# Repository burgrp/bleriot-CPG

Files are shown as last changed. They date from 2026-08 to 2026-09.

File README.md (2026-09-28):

# BleRiot Circulation Pump Group Controller

CPG is a mains-powered BleRiot node for controlling a circulation pump and a
motorized 3-way or 4-way valve in floor-heating and radiator-heating circuits.
It provides one switched output for the pump and two interlocked directional
outputs for a reversible valve actuator.

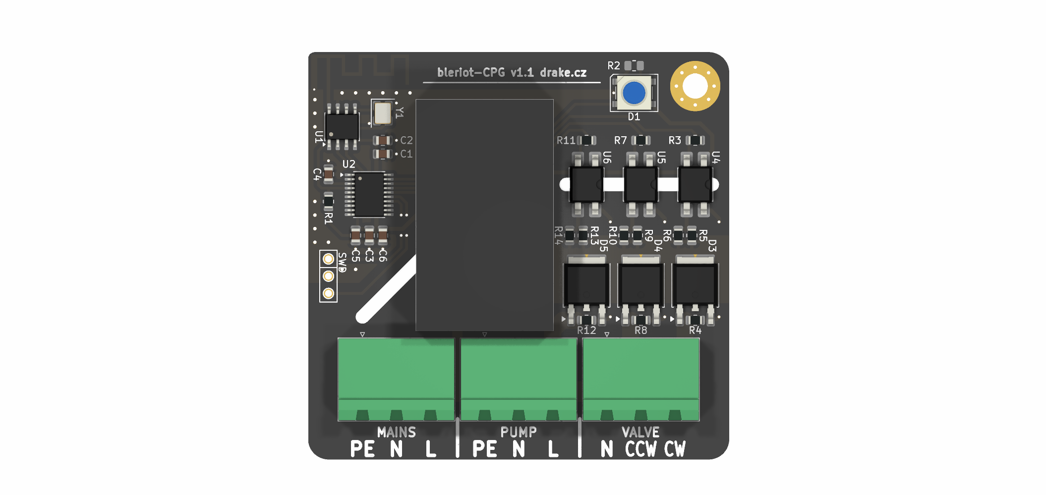
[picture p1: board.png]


The board is intended for supervisory heating control. Its triac channels are
on/off outputs; they are not phase-angle dimmers.

## Functions

- Circulation pump on/off control.
- Clockwise and counter-clockwise valve actuation.
- Firmware interlock preventing both valve directions from being energized at
  the same time.
- 100 ms break-before-make delay when changing valve direction; the latest
  command received during the delay wins.
- PAN2110 sub-GHz radio running the BleRiot register protocol.
- WS2812 status LED for local state indication.
- Onboard PY32F030 microcontroller and mains-to-3.3 V power module.

This arrangement supports common motorized mixing and diverting valves whose
actuator has a neutral connection and separate CW and CCW live inputs. Confirm
the actuator wiring and required reversal delay against its documentation.

## Connections

Connector numbering follows the KiCad schematic and PCB footprints.

| Connector | Pin | Function |
| --- | ---: | --- |
| J1 `MAINS` | 1 | Protective earth (PE) |
| J1 `MAINS` | 2 | Neutral (N) |
| J1 `MAINS` | 3 | Line (L) |
| J2 `VALVE` | 1 | Valve neutral (N) |
| J2 `VALVE` | 2 | Valve CCW switched live |
| J2 `VALVE` | 3 | Valve CW switched live |
| J3 `PUMP` | 1 | Protective earth (PE) |
| J3 `PUMP` | 2 | Pump neutral (N) |
| J3 `PUMP` | 3 | Pump switched live |

The three switched outputs use BTA08S-600CW triacs driven through MOC306x
optotriacs. The pump channel is independent. Valve CW and CCW share a firmware
interlock and must also be treated as mutually exclusive by any external
controller.

## BleRiot Registers

| Tag | Name | Type | Meaning |
| ---: | --- | --- | --- |
| 1 | `vcw` | bool | Valve clockwise output |
| 2 | `vccw` | bool | Valve counter-clockwise output |
| 3 | `pump` | bool | Circulation pump output |

A value of `0` is off and `1` is on. During valve reversal both valve registers
report off until the dead time expires and the pending direction is energized.
Null and unknown writes are ignored, and other boolean values are normalized to
`1`. The former test-only LED register is retired.

While the BleRiot link is online, the status LED is automatic:

| Operating state | LED indication |
| --- | --- |
| All outputs off | Amber (`0xa05000`) |
| Pump on, no valve active | Green (`0x00ff10`) |
| Valve CW active | Red (`0xff000a`) |
| Valve CCW active | Blue (`0x0020ff`) |

Valve state has priority over pump state. During valve dead time, the LED shows
the pump indication when the pump is on and the idle indication otherwise.
Before the first valid packet, and after five seconds without a valid packet,
the link is offline and the LED blinks red-orange (`0xff3000`): 200 ms on and
800 ms off. Link loss does not change the commanded pump or valve state.

## Firmware And Pin Mapping

The firmware targets a PY32F030F1 MCU and controls a PAN2110 radio over
three-wire SPI.

| Function | MCU pin | Schematic net | Behavior |
| --- | --- | --- | --- |
| Pump | PB4 | `PUMP` | Active-low output |
| Valve CCW | PB5 | `VALVE_CCW` | Active-low output |
| Valve CW | PB6 | `VALVE_CW` | Active-low output |
| Status LED | PB7 | `LED` | WS2812 data |
| PAN2110 CSN | PF3 | `~RF_CS` | Active-low chip select |
| PAN2110 SCK | PA2 | `RF_SCK` | Clock |
| PAN2110 data | PA3 | `RF_DATA` | Bidirectional data |

At startup, firmware preloads PB4-PB6 high before changing them to outputs so
the active-low optotriac inputs remain off. All three switched outputs start
off. The status LED uses the offline heartbeat until a valid packet is received.

There is no mains zero-cross input. The MOC306x optotriacs shown in the
schematic are zero-cross devices, so these channels provide on/off switching
only.

## Repository Layout

- [`board/`](board/) contains the KiCad schematic, PCB, BOM, and fabrication
  outputs.
- [`fw/`](fw/) contains the importable `cpg` TinyGo firmware and board-owned
  build profile.
- [`fw/spec/`](fw/spec/) contains the configuration, register contract, chip,
  and firmware manifest.
- [`fw/cmd/dev/`](fw/cmd/dev/) contains the local inventory and BleRiot CLI.
- [`burgrp/tinygo-drivers/ws2812`](https://github.com/burgrp/tinygo-drivers/tree/main/ws2812)
  contains the reusable 24 MHz PY32 WS2812 driver.
- [`sub/hw-kicad/`](sub/hw-kicad/) is the shared KiCad library submodule.

Initialize the hardware library after cloning:

```bash
git submodule update --init --recursive
```

## Build And Test

The firmware requires Go, TinyGo with the PY32 target support used by this
project, GNU Arm Embedded binutils, and pyOCD with the Puya device pack.

```bash
cd fw
go test ./...
go run ./cmd/dev node gen --name cpg
go run ./cmd/dev node build --name cpg --disassembly
```

BleRiot generates a private entry point under `.bleriot/firmware/cpg` and calls
`cpg.Run` with the configured identity and `spec.Config`. The firmware profile
selects `py32f030x8`, scheduler-none, leaking GC, RTT serial, and a 100 kHz pyOCD
connection.

The first board was programmed through a WCH-Link at 100 kHz using an
under-reset connection. With the board connected:

```bash
cd fw
go run ./cmd/dev node install-pack --name cpg
go run ./cmd/dev node build --name cpg --flash --rtt
```

Confirm the fitted MCU density before relying on the `py32f030x8` target. Check
the physical board before using X1: older board revisions route the SWD header
labels to the wrong MCU pins and do not expose target voltage or reset.

## Hardware Status

The current firmware has been built, flashed, and exercised on the board:

- PAN2110 startup was confirmed over RTT on BleRiot channel 37 with spread
  factor S8.
- Safe startup was confirmed with pump, CW, and CCW outputs all off.
- The valve interlock and latest-command state machine are covered by host
  tests.
- The WS2812 waveform and all RGB channels were validated at 3.3 V.

End-to-end testing with the intended pump, valve actuator, heating controller,
and RF hub is still required for each installation.

## Safety

This design connects directly to hazardous mains voltage. Assembly,
installation, testing, and enclosure work must be performed by suitably
qualified people using applicable electrical codes and safe isolation
practices.

Before deployment, independently verify at least:

- Input fusing and upstream over-current protection.
- PCB creepage and clearance for the applicable mains category.
- Protective-earth continuity and enclosure construction.
- Triac current, thermal, and inductive-load commutation margins.
- The exact MOC306x trigger-current grade and the fitted 270 ohm input resistor.
- WS2812 operation at 3.3 V, below the linked part's specified supply range.
- Pump and valve actuator voltage, current, wiring, and duty-cycle limits.
- Required valve reversal delay and behavior after RF or controller loss.

Outputs retain their commanded state until another command or reset. Define
radio-loss behavior and maximum pump and valve run times for the installation.

Do not connect a pump, valve, or mains supply based only on the connector table;
verify the assembled board against the schematic, PCB, and the equipment
manufacturer's wiring documentation.

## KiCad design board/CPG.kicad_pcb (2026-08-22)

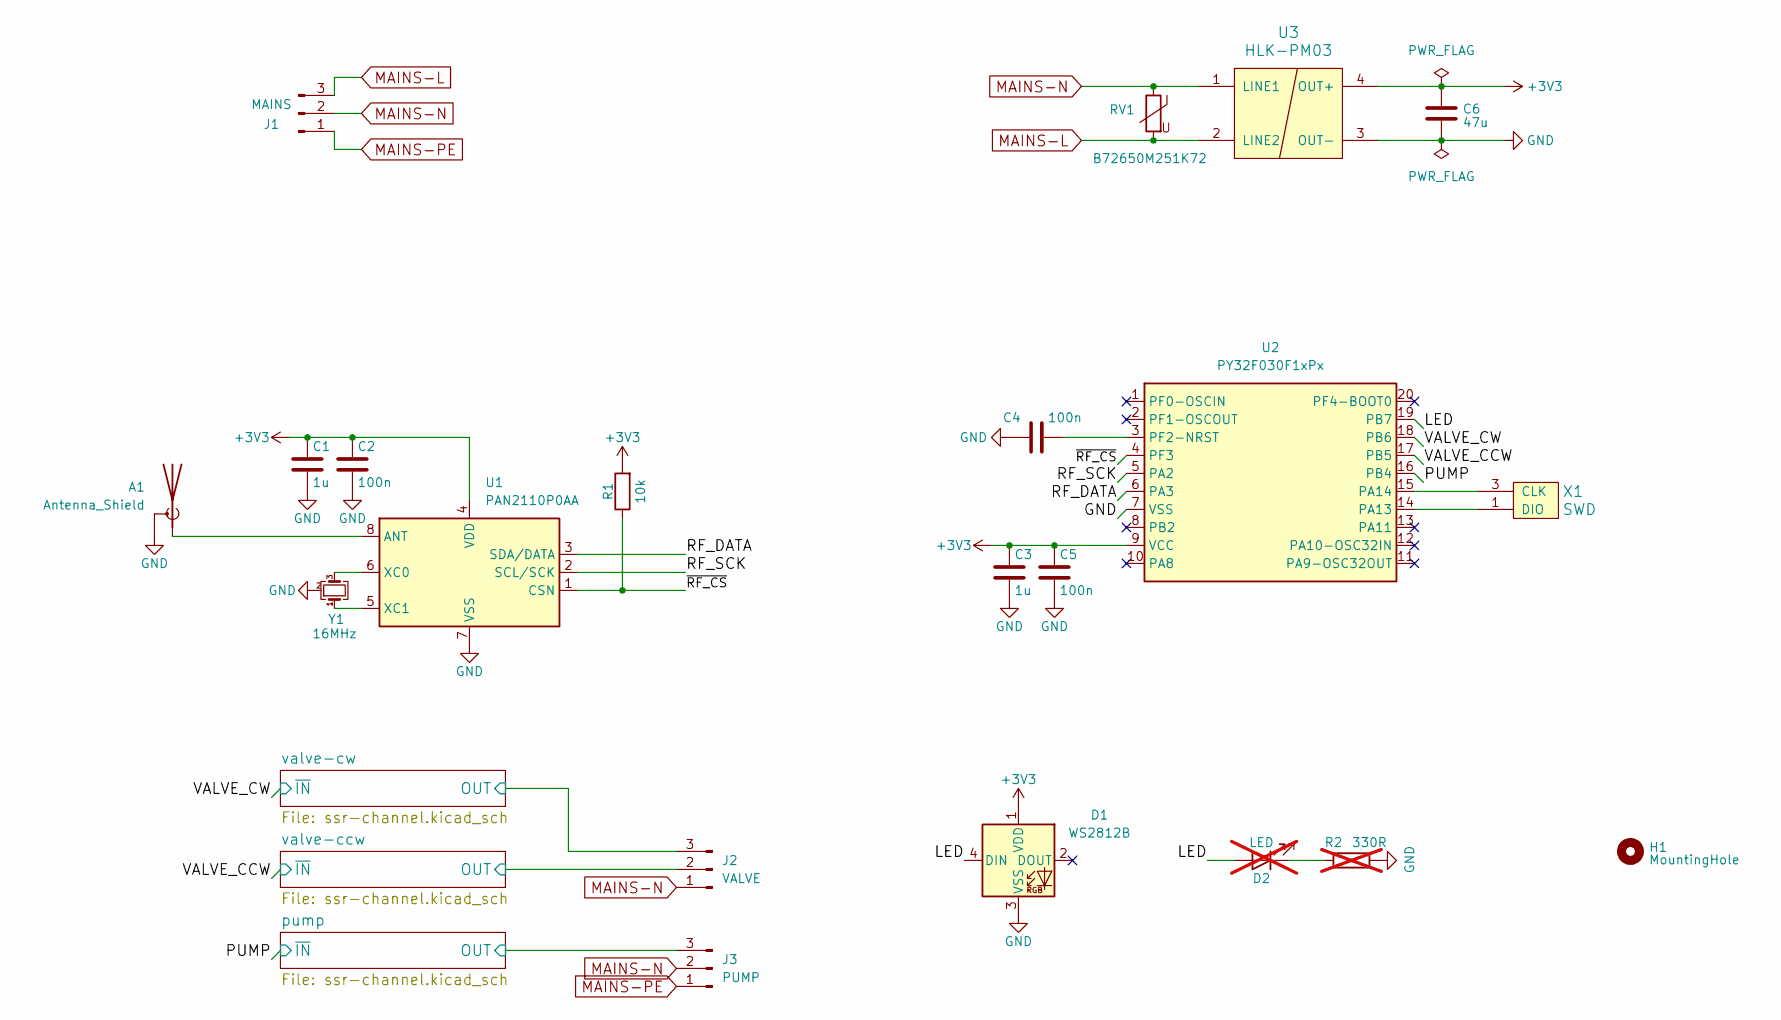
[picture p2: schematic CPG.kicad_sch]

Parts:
A1: Antenna_Shield; Texas_SWRA117D_2.4GHz_Right
C1, C3: 1u; C_0805_2012Metric
C2, C4, C5: 100n; C_0805_2012Metric
C6: 47u; C_0805_2012Metric
D1: WS2812B; LED_WS2812B_PLCC4_5.0x5.0mm_P3.2mm
D2: LED; LED_0805_2012Metric_Pad1.15x1.40mm_HandSolder; not fitted
H1: MountingHole; MountingHole_3.7mm_Pad_Via
J1: MAINS; PhoenixContact_MSTBA_2,5_3-G_1x03_P5.00mm_Horizontal
J2: VALVE; PhoenixContact_MSTBA_2,5_3-G_1x03_P5.00mm_Horizontal
J3: PUMP; PhoenixContact_MSTBA_2,5_3-G_1x03_P5.00mm_Horizontal
R1: 10k; R_0805_2012Metric
R2: 330R; R_0805_2012Metric; not fitted
RV1: B72650M251K72; R_1210_3225Metric
U1: PAN2110P0AA; SOIC-8_3.9x4.9mm_P1.27mm
U2: PY32F030F1xPx; TSSOP-20_4.4x6.5mm_P0.65mm
U3: HLK-PM03; HLK-PM01
X1: SWD
Y1: 16MHz; Crystal_SMD_3225-4Pin_3.2x2.5mm

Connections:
+3V3: C1.1, C2.1, C3.1, C5.1, C6.1, D1.1 (VDD), R1.2, U1.4 (VDD), U2.9 (VCC), U3.4 (OUT+); also elsewhere on the board
/LED: D1.4 (DIN), D2.2 (A), U2.19 (PB7)
/PUMP: U2.16 (PB4); also elsewhere on the board
/RF_DATA: U1.3 (SDA/DATA), U2.6 (PA3)
/RF_SCK: U1.2 (SCL/SCK), U2.5 (PA2)
/VALVE_CCW: U2.17 (PB5); also elsewhere on the board
/VALVE_CW: U2.18 (PB6); also elsewhere on the board
/pump/OUT: J3.3; also elsewhere on the board
/valve-ccw/OUT: J2.2; also elsewhere on the board
/valve-cw/OUT: J2.3; also elsewhere on the board
/~RF_CS: R1.1, U1.1 (CSN), U2.4 (PF3)
GND: A1.2 (Shield), C1.2, C2.2, C3.2, C4.2, C5.2, C6.2, D1.3 (VSS), R2.1, U1.7 (VSS), U2.7 (VSS), U3.3 (OUT-), X1.2 (GND), Y1.2 (G), Y1.4 (G)
MAINS-L: J1.3, RV1.2, U3.2 (LINE2); also elsewhere on the board
MAINS-N: J1.2, J2.1, J3.2, RV1.1, U3.1 (LINE1)
MAINS-PE: J1.1, J3.1
unnamed: A1.1 (A), U1.8 (ANT)
unnamed: D2.1 (K), R2.2
unnamed: U1.6 (XC0), Y1.3
unnamed: U1.5 (XC1), Y1.1
unnamed: U2.14 (PA13), X1.1 (DIO)
unnamed: U2.15 (PA14), X1.3 (CLK)
unnamed: C4.1, U2.3 (PF2-NRST)

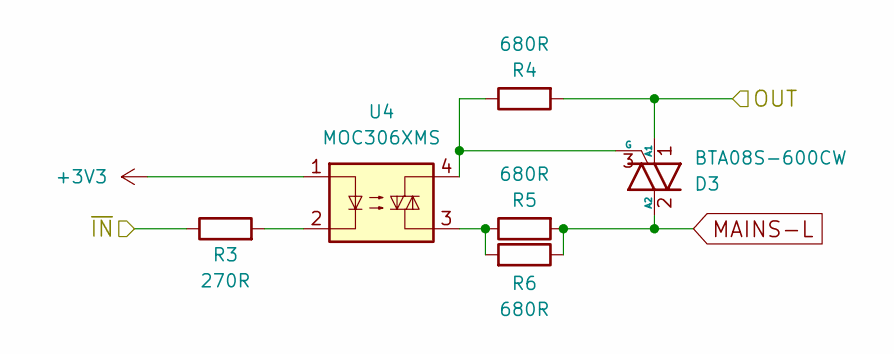
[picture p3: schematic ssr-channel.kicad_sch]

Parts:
D3: BTA08S-600CW; TO-252-2
R3: 270R; R_0805_2012Metric
R4, R5, R6: 680R; R_0805_2012Metric
U4: MOC306XMS; SMDIP-4_W7.62mm

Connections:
+3V3: U4.1; also elsewhere on the board
/VALVE_CW: R3.1; also elsewhere on the board
/valve-cw/OUT: D3.1 (A1), R4.2; also elsewhere on the board
MAINS-L: D3.2 (A2), R5.2, R6.1; also elsewhere on the board
unnamed: D3.3 (G), R4.1, U4.4
unnamed: R3.2, U4.2
unnamed: R5.1, R6.2, U4.3

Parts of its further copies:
D4, D5: BTA08S-600CW; TO-252-2
R7, R11: 270R; R_0805_2012Metric
R8, R9, R10, R12, R13, R14: 680R; R_0805_2012Metric
U5, U6: MOC306XMS; SMDIP-4_W7.62mm

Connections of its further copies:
+3V3: U5.1, U6.1; also elsewhere on the board
/PUMP: R11.1; also elsewhere on the board
/VALVE_CCW: R7.1; also elsewhere on the board
/pump/OUT: D5.1 (A1), R12.2; also elsewhere on the board
/valve-ccw/OUT: D4.1 (A1), R8.2; also elsewhere on the board
MAINS-L: D4.2 (A2), D5.2 (A2), R9.2, R10.1, R13.2, R14.1; also elsewhere on the board
unnamed: D4.3 (G), R8.1, U5.4
unnamed: D5.3 (G), R12.1, U6.4
unnamed: R7.2, U5.2
unnamed: R9.1, R10.2, U5.3
unnamed: R11.2, U6.2
unnamed: R13.1, R14.2, U6.3

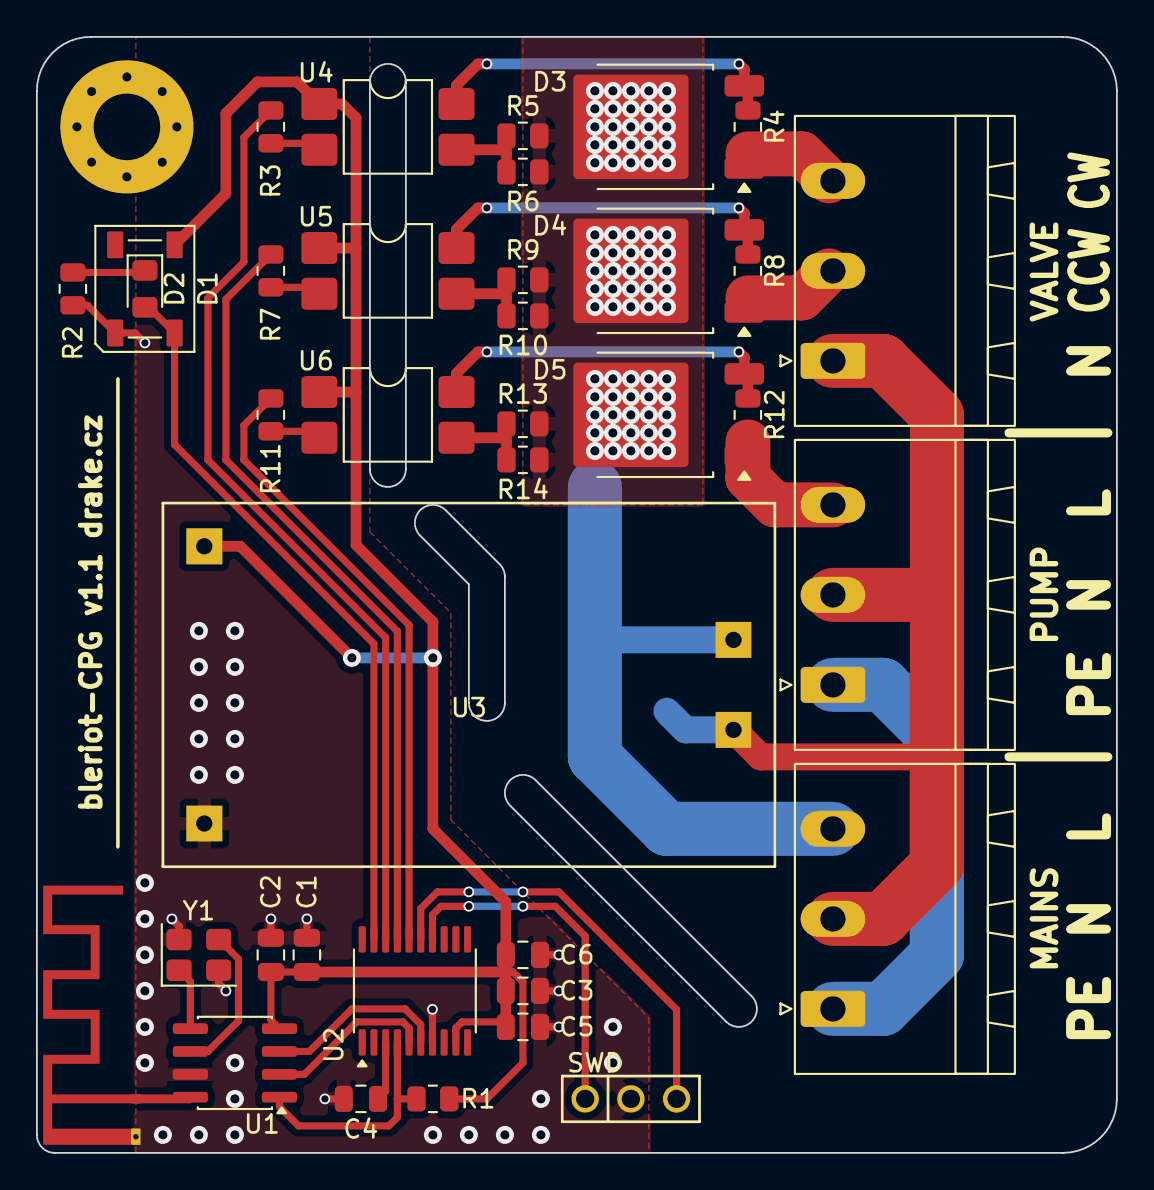
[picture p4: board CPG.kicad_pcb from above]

Board: 2 copper layers, 60.0 x 62.0 mm, 39 parts (1 on the bottom side), 31 nets.

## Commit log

2026-08-02 initial commit (derived from SSR5A)
    [CPG.kicad_pcb, CPG.kicad_sch, ssr-channel.kicad_sch]
2026-08-22 Add CPG firmware and correct SWD header
    [CPG.kicad_pcb, CPG.kicad_sch]
2026-08-22 Add new segments and vias for U2-PA14 net in PCB layout
    [CPG.kicad_pcb]
2026-09-23 Add RF link status LED indication
2026-09-28 fix(fw): recalibrate status LED colors
2026-11-03 fix(fw): match REG6 status LED colors
